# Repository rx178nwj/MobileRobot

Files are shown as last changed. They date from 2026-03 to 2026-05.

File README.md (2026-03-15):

# Mobile Robot

4輪駆動移動ロボットプロジェクト - ROS 2、Python WebSocket サービス、PR2040 モータードライバを使用

## プロジェクト概要

このプロジェクトは、Raspberry Pi と PR2040 マイコンを使用した移動ロボットシステムです。ROS 2 (Jazzy) を Docker コンテナで実行し、Python ベースの Edge Services を介してハードウェアと通信します。

### 主な特徴

- **ROS 2 Jazzy** - Docker コンテナで実行（Debian 13 ホスト）
- **WebSocket 通信** - ROS 2 と Edge Services 間の通信
- **USB シリアル制御** - PR2040 モータードライバとの通信
- **リアルタイムオドメトリ** - 50Hz でのエンコーダベース位置推定
- **差動駆動制御** - 4輪駆動の差動駆動キネマティクス
- **速度制御モード** - PR2040 ファームウェアによる PID 速度制御

## システムアーキテクチャ

```
┌─────────────────────────────────────────────────────────────┐
│                    ROS 2 (Docker Container)                  │
│  ┌──────────────┐  ┌──────────────┐  ┌──────────────┐      │
│  │ ws_motor_    │  │ ws_odometry_ │  │ robot_state_ │      │
│  │ controller   │  │ publisher    │  │ publisher    │      │
│  └──────┬───────┘  └───────▲──────┘  └──────────────┘      │
└─────────┼──────────────────┼────────────────────────────────┘
          │                  │
       WebSocket          WebSocket
       (port 8001)        (port 8002)
          │                  │
          ▼                  ▼
┌─────────────────────────────────────────────────────────────┐
│                      Edge Services (Host)                    │
│  ┌──────────────┐  ┌──────────────┐  ┌──────────────┐      │
│  │ Motor        │  │ Odometry     │  │ Camera       │      │
│  │ Service      │  │ Service      │  │ Service      │      │
│  └──────┬───────┘  └───────▲──────┘  └──────────────┘      │
└─────────┼──────────────────┼────────────────────────────────┘
          │                  │
       USB Serial        USB Serial
       (/dev/ttyACM0)    (/dev/ttyACM0)
          │                  │
          ▼                  ▼
┌─────────────────────────────────────────────────────────────┐
│                  PR2040 Motor Driver                         │
│  ┌──────────┐  ┌──────────┐  ┌──────────┐  ┌──────────┐   │
│  │ Motor 0  │  │ Motor 1  │  │ Motor 2  │  │ Motor 3  │   │
│  │ (動作OK) │  │ (動作OK) │  │ (故障)   │  │ (故障)   │   │
│  └──────────┘  └──────────┘  └──────────┘  └──────────┘   │
└─────────────────────────────────────────────────────────────┘
```

## ハードウェア

- **Raspberry Pi 4** - メインコントローラ
- **PR2040 (RP2040)** - モータードライバマイコン
- **JGA25-370 モーター** - ギア比 51:1、エンコーダ付き
- **車輪**: 直径 66mm (半径 33mm)
- **ホイールベース**: 160mm

### キャリブレーション値

- **エンコーダ CPR**: 827.2 counts/revolution（キャリブレーション済み）
- **ギア比**: 54.78:1（実測値、ファームウェアに組み込み済み）
- **車輪円周**: 212.06mm
- **変換係数**: 0.2564 mm/count

## ディレクトリ構成

```
MobileRobot/
├── edge_services/              # Python WebSocket サービス
│   ├── hardware/              # ハードウェアドライバ
│   │   ├── pr2040_usb_driver.py    # USB シリアルドライバ (使用中)
│   │   └── pr2040_driver.py        # I2C ドライバ (非推奨)
│   ├── config/                # 設定ファイル
│   │   └── robot_config.json  # ロボット設定
│   ├── motor_service.py       # モーター制御サービス (WS:8001)
│   ├── odometry_service.py    # オドメトリサービス (WS:8002)
│   ├── camera_service.py      # カメラサービス (WS:8003)
│   └── launch_all.py          # 全サービス起動スクリプト
│
├── ros2_docker/               # ROS 2 Docker 環境
│   ├── Dockerfile             # ROS 2 Jazzy イメージ
│   └── docker-compose.yml     # Docker Compose 設定
│
├── mobile_robot_edge/         # ROS 2 パッケージ
│   ├── mobile_robot_edge/
│   │   ├── ws_motor_controller.py      # /cmd_vel → WS ブリッジ
│   │   └── ws_odometry_publisher.py    # WS → /odom ブリッジ
│   ├── launch/
│   │   └── ws_edge_bringup.launch.py   # 起動ファイル
│   ├── urdf/
│   │   └── mobile_robot.urdf           # ロボットモデル
│   ├── package.xml
│   └── setup.py
│
├── MotorDriver/               # PR2040 ファームウェア
│   └── Firmware/
│       └── PR2040_MotorDriver/
│           ├── PR2040_MotorDriver.ino  # メインファームウェア
│           └── CommandReference.md     # 通信プロトコル仕様
│
├── docs/                      # ドキュメント
│   └── raspberry_pi_setup.md  # Raspberry Pi セットアップガイド
│
└── test_*.py                  # 各種テストスクリプト
```

## セットアップ

### クイックスタート

```bash
# 1. リポジトリのクローン
git clone https://github.com/rx178nwj/MobileRobot.git
cd MobileRobot

# 2. 詳細なセットアップ手順に従う
# docs/raspberry_pi_setup.md を参照してください
```

### 詳細なセットアップ

完全なセットアップ手順については、以下のドキュメントを参照してください:

📚 **[Raspberry Pi セットアップガイド](docs/raspberry_pi_setup.md)**

このガイドには以下が含まれます:
- システム要件
- Docker インストール
- Python 環境セットアップ
- ハードウェア接続確認
- Edge Services セットアップ
- ROS 2 Docker 環境セットアップ
- システムの起動方法
- トラブルシューティング

## 使い方

### システムの起動

#### 1. Edge Services の起動（ターミナル 1）

```bash
cd ~/MobileRobot/edge_services
python3 launch_all.py
```

#### 2. ROS 2 システムの起動（ターミナル 2）

```bash
cd ~/MobileRobot/ros2_docker
docker compose run --rm ros2 bash -c "
    source /opt/ros/jazzy/setup.bash && \
    source /home/pi/ros2_ws/install/setup.bash && \
    ros2 launch mobile_robot_edge ws_edge_bringup.launch.py
"
```

#### 3. ロボットの制御（ターミナル 3）

```bash
cd ~/MobileRobot/ros2_docker
docker compose run --rm ros2 bash

# コンテナ内で
source /opt/ros/jazzy/setup.bash
source /home/pi/ros2_ws/install/setup.bash

# 前進コマンド
ros2 topic pub --once /cmd_vel geometry_msgs/msg/Twist \
    "{linear: {x: 0.1, y: 0.0, z: 0.0}, angular: {x: 0.0, y: 0.0, z: 0.0}}"

# オドメトリの確認
ros2 topic echo /odom
```

### テスト

#### 総合テストスイート

```bash
cd ~/MobileRobot
python3 test_usb_services.py
```

#### モーター個別テスト

```bash
# 各モーターを個別にテスト（DIRECT モード）
python3 test_motors_complete.py --test direct

# 10cm 前進テスト（VELOCITY モード）
python3 test_motors_complete.py --test velocity
```

#### USB 通信テスト

```bash
# 基本的な USB 通信テスト
python3 test_pr2040_usb_fixed.py --test basic

# 10cm 移動テスト
python3 test_pr2040_usb_fixed.py --test move
```

## 通信プロトコル

### USB シリアルプロトコル

PR2040 との通信は以下のパケット形式を使用:

```
[0xAA][CMD][LEN][DATA...][CHECKSUM]
```

- **Header**: 0xAA（固定）
- **CMD**: コマンドバイト
- **LEN**: データ長
- **DATA**: コマンドデータ
- **CHECKSUM**: XOR チェックサム（CMD ^ LEN ^ DATA[0] ^ ... ^ DATA[LEN-1]）

詳細は [CommandReference.md](MotorDriver/Firmware/PR2040_MotorDriver/CommandReference.md) を参照。

### WebSocket プロトコル

#### モーター制御（ポート 8001）

```json
{
  "type": "cmd_vel",
  "linear": 0.1,    // m/s
  "angular": 0.5    // rad/s
}
```

#### オドメトリ（ポート 8002）

```json
{
  "type": "odom",
  "timestamp": 1234567.89,
  "pose": {
    "x": 0.0,       // meters
    "y": 0.0,       // meters
    "theta": 0.0    // radians
  },
  "twist": {
    "linear": 0.0,  // m/s
    "angular": 0.0  // rad/s
  },
  "encoders": [100, 100, 0, 0]
}
```

## 既知の問題

### ハードウェア

- **モーター 2 と 3**: ハードウェアの問題により動作しません（エンコーダ値が常に 0）
- **モーター 0 と 1**: 正常に動作します

### 対応予定

これらのハードウェア問題は、モータードライバボードまたは配線の問題と考えられます。

## 開発状況

### 完了

- ✅ PR2040 ファームウェア（USB シリアル + I2C）
- ✅ USB シリアルドライバ
- ✅ Edge Services（モーター制御、オドメトリ、カメラ）
- ✅ ROS 2 Docker 環境
- ✅ WebSocket ブリッジ
- ✅ 基本的な動作確認

### 今後の予定

- ⏳ IMU センサー統合
- ⏳ カメラ画像処理
- ⏳ ナビゲーションスタック（Nav2）
- ⏳ SLAM（地図作成と自己位置推定）
- ⏳ 自律ナビゲーション

## ライセンス

このプロジェクトは MIT ライセンスの下で公開されています。

## 貢献

プルリクエストを歓迎します。大きな変更の場合は、まず issue を開いて変更内容を議論してください。

## 作者

- GitHub: [@rx178nwj](https://github.com/rx178nwj)

## 謝辞

- ROS 2 コミュニティ
- Raspberry Pi Foundation
- Arduino/RP2040 コミュニティ

---

**最終更新日**: 2026-03-15

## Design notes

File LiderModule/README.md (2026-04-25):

# LiderModule

LiderModule is a low-cost 3D LiDAR scanner module for a mobile robot. It tilts a 2D YDLIDAR T-mini Pro with a FEETECH STS3215 servo, reads MPU6050 attitude data on the ESP32-S3, and sends scan slices to a Raspberry Pi over USB CDC.

Design policy:

- LiderModule firmware focuses on sensing quality (LiDAR + tilt angle + IMU + timing consistency).
- Environment understanding (step/hole detection, risk decision, vehicle action) is implemented on Raspberry Pi side.

## Implementation Status

Implemented:

- ESP32-S3 Arduino firmware in `firmware/lidar_tilt_3d/lidar_tilt_3d.ino`
- Raspberry Pi host CLI in `host/rpi_tilt_3d.py`
- Binary USB CDC framing compatible with `SPEC.md`
- IMU packets, 3D scan status packets, 3D scan slice packets
- Manual tilt command and automatic tilt scan command
- Point-cloud transform, CSV export, PLY export, and optional Open3D/matplotlib visualization

Needs hardware validation:

- Exact YDLIDAR T-mini Pro packet distance scaling and checksum behavior
- SCServo library API compatibility for the installed Arduino library version
- Servo direction and center position on the assembled mechanism
- Final IMU sign convention after physical mounting

The requirements are implementable, but those items depend on the actual hardware, library version, and mounting orientation.

## Layout

```text
LiderModule/
  SPEC.md
  README.md
  firmware/
    lidar_tilt_3d/
      lidar_tilt_3d.ino
  host/
    rpi_tilt_3d.py
    requirements.txt
    test_protocol.py
  docs/
    wiring.md
```

## Firmware Setup

1. Install Arduino IDE 2.x.
2. Select `Seeed Studio XIAO ESP32-S3`.
3. Enable `USB CDC On Boot`.
4. Install the `SCServo` library.
5. Open `firmware/lidar_tilt_3d/lidar_tilt_3d.ino`.
6. Upload to the XIAO ESP32-S3.

Important serial assignments:

- `Serial`: USB CDC to Raspberry Pi
- `Serial0`: STS3215 servo bus, 1 Mbps, GPIO44 RX / GPIO43 TX
- `LidarSerial`: YDLIDAR, 230400 bps, GPIO3 RX / GPIO4 TX

## Host Setup

```bash
cd LiderModule/host
python3 -m venv .venv
. .venv/bin/activate
pip install -r requirements.txt
```

Default scan (continuous sweep, no step-stop):

```bash
python3 rpi_tilt_3d.py --port /dev/ttyACM0
```

Save a PLY point cloud:

```bash
python3 rpi_tilt_3d.py --tilt-min -45 --tilt-max 45 --step 2 --save scan.ply
```

Save CSV without visualization:

```bash
python3 rpi_tilt_3d.py --step 2 --save scan.csv --no-viz
```

Visualize saved result (.csv / .ply):

```bash
python3 host/visualize_scan_result.py scan.ply --mode matplotlib
python3 host/visualize_scan_result.py scan.csv --mode both --equal-axis
python3 host/visualize_scan_result.py scan.ply --save-png scan_summary.png --no-show
```

Continuous live visualization (for remote desktop):

```bash
python3 host/live_scan_viewer.py --port /dev/ttyACM0 --tilt-min -45 --tilt-max 45 --step 2 --equal-axis --auto-recover
```

`live_scan_viewer.py` のウィンドウ右下に `Clear` ボタンがあり、押すと表示中の点群だけをクリアします（計測は継続）。
同ウィンドウには `Height-wise Y Graph (Y-Z)` が追加され、高さ(Z)ごとのY分布を確認できます。

Downward hazard monitoring example on Raspberry Pi side:

```bash
python3 host/downward_hazard_monitor.py --port /dev/ttyACM1 --tilt-min -45 --tilt-max 0 --step 2 --duration-sec 20 --save-png downward_hazard_summary.png
```

This mode continuously scans the downward sector and prints hazard status (`SAFE` / `STEP_DOWN` / `HOLE`) while running.

Manual tilt test:

```bash
python3 rpi_tilt_3d.py --manual-tilt 30.0 --no-viz
```

## Protocol Summary

Frames use:

```text
[0xFE][0xEF][TYPE][LEN_L][LEN_H][PAYLOAD...][CHECKSUM]
```

The checksum is XOR of `TYPE`, `LEN_L`, `LEN_H`, and all payload bytes.

Device to host:

- `0x02`: IMU data, `<float pitch><float roll><float yaw>`
- `0x04`: scan slice, `<float tilt_cmd><float tilt_start><float tilt_end><float imu_pitch><float imu_roll><uint16 count><points...>`
- `0x05`: scan status, `<uint8 state><uint16 step><uint16 total>`

Host to device:

- `0x10`: manual servo angle, `<float angle_deg>`
- `0x12`: scan start, `<float tilt_min><float tilt_max><float step>`
- `0x13`: scan stop, empty payload

## Validation

Host-side syntax and protocol tests:

```bash
cd LiderModule/host
python -m py_compile rpi_tilt_3d.py test_protocol.py
python -m unittest test_protocol.py
```

Firmware validation must be completed in Arduino IDE or `arduino-cli` with the target board package and `SCServo` installed.

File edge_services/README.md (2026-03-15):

# Edge Services

シンプルなPythonベースのモバイルロボットエッジ制御サービス

## 概要

Raspberry Pi上で動作する軽量なロボット制御サービス群です。ROS 2を使用せず、WebSocket通信で外部PCと連携します。

### アーキテクチャ

```
外部PC (ROS 2)  ←→  WebSocket  ←→  Raspberry Pi (Edge Services)
                                          ↓ I2C
                                    PR2040 Motor Driver
```

## 機能

### 1. モーター制御サービス (`motor_service.py`)
- WebSocketで速度指令を受信
- 差動駆動キネマティクス
- I2C経由でPR2040モータードライバ制御
- 安全タイムアウト機能

**WebSocket**: `ws://raspberrypi.local:8001`

**メッセージフォーマット**:
```json
{
  "type": "cmd_vel",
  "linear": 0.2,   // m/s
  "angular": 0.5   // rad/s
}
```

### 2. オドメトリサービス (`odometry_service.py`)
- エンコーダ読み取り (I2C)
- オドメトリ計算 (位置・速度)
- WebSocketで配信 (50Hz)

**WebSocket**: `ws://raspberrypi.local:8002`

**メッセージフォーマット**:
```json
{
  "type": "odom",
  "timestamp": 1234567.89,
  "pose": {
    "x": 0.0,      // meters
    "y": 0.0,      // meters
    "theta": 0.0   // radians
  },
  "twist": {
    "linear": 0.0,  // m/s
    "angular": 0.0  // rad/s
  },
  "encoders": [0, 0, 0, 0]
}
```

### 3. カメラサービス (`camera_service.py`)
- Raspberry Pi Camera Module 3から画像取得
- オートフォーカス無効化 (SLAM用)
- JPEG圧縮配信
- WebSocket配信 (30fps)

**WebSocket**: `ws://raspberrypi.local:8003`

**メッセージフォーマット**: バイナリ (ヘッダー8バイト + JPEGデータ)

## ファイル構成

```
edge_services/
├── hardware/
│   ├── __init__.py
│   └── pr2040_driver.py      # PR2040 I2C通信ライブラリ
├── config/
│   └── robot_config.json     # ロボット設定
├── logs/                     # ログファイル
├── motor_service.py          # モーター制御サービス
├── odometry_service.py       # オドメトリサービス
├── camera_service.py         # カメラサービス
├── launch_all.py             # 全サービス起動スクリプト
├── requirements.txt          # Python依存関係
└── README.md                 # 本ドキュメント
```

## セットアップ

### 1. 依存パッケージのインストール

```bash
cd /home/pi/MobileRobot/edge_services

# Pythonパッケージ
pip3 install -r requirements.txt

# システムパッケージ
sudo apt install -y python3-opencv i2c-tools v4l-utils
```

### 2. I2C有効化

```bash
# raspi-configでI2Cを有効化
sudo raspi-config
# Interface Options → I2C → Yes

# I2Cデバイス確認
i2cdetect -y 1
# 0x60にPR2040が表示されるはず
```

### 3. カメラ設定

```bash
# カメラデバイス確認
ls -l /dev/video0

# カメラ情報確認
v4l2-ctl -d /dev/video0 --all

# フォーカス値の調整（オプション）
v4l2-ctl -d /dev/video0 --set-ctrl=focus_automatic_continuous=0
v4l2-ctl -d /dev/video0 --set-ctrl=focus_absolute=450
```

### 4. 設定ファイル編集

`config/robot_config.json`を編集してロボットパラメータを調整:

```json
{
  "robot": {
    "wheel_base": 0.16,     // 車輪間距離 (m)
    "wheel_radius": 0.033,  // 車輪半径 (m)
    "encoder_cpr": 720      // エンコーダ分解能
  }
}
```

## 起動方法

### すべてのサービスを起動

```bash
cd /home/pi/MobileRobot/edge_services
python3 launch_all.py
```

### 個別サービスの起動

```bash
# モーター制御のみ
python3 motor_service.py

# オドメトリのみ
python3 odometry_service.py

# カメラのみ
python3 camera_service.py
```

### systemdサービスとして登録（自動起動）

```bash
# サービスファイル作成
sudo nano /etc/systemd/system/edge-services.service
```

```ini
[Unit]
Description=Mobile Robot Edge Services
After=network.target

[Service]
Type=simple
User=pi
WorkingDirectory=/home/pi/MobileRobot/edge_services
ExecStart=/usr/bin/python3 /home/pi/MobileRobot/edge_services/launch_all.py
Restart=on-failure
RestartSec=5

[Install]
WantedBy=multi-user.target
```

```bash
# サービス有効化
sudo systemctl daemon-reload
sudo systemctl enable edge-services
sudo systemctl start edge-services

# ステータス確認
sudo systemctl status edge-services

# ログ確認
sudo journalctl -u edge-services -f
```

## テスト

### WebSocketテスト (Python)

```python
import asyncio
import websockets
import json

async def test_motor():
    uri = "ws://localhost:8001"
    async with websockets.connect(uri) as ws:
        # 前進指令
        cmd = {"type": "cmd_vel", "linear": 0.2, "angular": 0.0}
        await ws.send(json.dumps(cmd))
        response = await ws.recv()
        print(f"Motor response: {response}")

async def test_odometry():
    uri = "ws://localhost:8002"
    async with websockets.connect(uri) as ws:
        # オドメトリ受信
        for i in range(10):
            msg = await ws.recv()
            data = json.loads(msg)
            print(f"Odom: x={data['pose']['x']:.3f} y={data['pose']['y']:.3f}")

asyncio.run(test_motor())
asyncio.run(test_odometry())
```

### I2C通信テスト

```bash
# PR2040ドライバテスト
cd /home/pi/MobileRobot/edge_services
python3 -c "from hardware.pr2040_driver import PR2040Driver; \
driver = PR2040Driver(); \
print('Temp:', driver.read_temperature()); \
print('Encoders:', driver.read_all_encoders()); \
driver.close()"
```

## トラブルシューティング

### I2C通信エラー

```bash
# I2Cデバイス確認
i2cdetect -y 1

# PR2040が0x60に表示されない場合:
# - 配線を確認
# - PR2040の電源を確認
# - I2Cプルアップ抵抗を確認
```

### カメラが起動しない

```bash
# カメラデバイス確認
ls -l /dev/video*

# カメラが検出されない場合:
sudo vcgencmd get_camera

# カメラを有効化
sudo raspi-config
# Interface Options → Camera → Yes
# 再起動が必要
```

### WebSocketに接続できない

```bash
# ポートが開いているか確認
sudo netstat -tuln | grep 800

# ファイアウォール確認（Debian/Raspberry Pi OSではデフォルトで無効）
sudo ufw status

# サービスログ確認
tail -f logs/edge_services.log
```

## 外部PCとの連携 (ROS 2ブリッジ)

外部PC側で ROS 2 ブリッジノードを作成すると、ROS 2 Navigation Stackと連携できます。

### ROS 2ブリッジノード例

```python
# 外部PC (ROS 2) 側
import rclpy
from rclpy.node import Node
from geometry_msgs.msg import Twist
from nav_msgs.msg import Odometry
import asyncio
import websockets

class EdgeBridgeNode(Node):
    def __init__(self):
        super().__init__('edge_bridge')

        # ROS 2トピック
        self.cmd_vel_sub = self.create_subscription(
            Twist, '/cmd_vel', self.cmd_vel_callback, 10)
        self.odom_pub = self.create_publisher(Odometry, '/odom', 10)

        # WebSocket接続 (Raspberry Pi)
        self.motor_ws = "ws://raspberrypi.local:8001"
        self.odom_ws = "ws://raspberrypi.local:8002"

    # ... 実装 ...
```

## パラメータ調整

### フォーカス値の最適化

ロボットの動作環境に応じてカメラのフォーカス値を調整:

- **近距離** (20-50cm): `focus_value: 200-350`
- **中距離** (50cm-2m): `focus_value: 400-500`
- **遠距離** (1m-∞): `focus_value: 500-650`

### PIDゲイン調整

PR2040ドライバでPIDゲインを調整可能:

```python
from hardware.pr2040_driver import PR2040Driver

driver = PR2040Driver()

# 速度PIDゲイン設定 (wheel_index, kp, ki, kd)
# デフォルト: kp=1.0, ki=0.05, kd=0.0
kp, ki, kd = 1.5, 0.1, 0.0
data = struct.pack('<Bfff', 0, kp, ki, kd)
driver._write_register(driver.REG_SET_VEL_PID, list(data))
```

## ライセンス

MIT

## 作者

rx178nwj

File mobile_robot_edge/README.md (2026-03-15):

# mobile_robot_edge

ROS 2 Humbleパッケージ - モバイルロボットのエッジ側制御（Raspberry Pi）

## 概要

このパッケージはRaspberry Pi上で動作し、センサーデータの取得とモーター制御を担当します。
重い処理（SLAM、ナビゲーション等）は別のPCで実行されることを想定しています。

## ハードウェア要件

- **SBC**: Raspberry Pi 4/5 (Ubuntu 22.04)
- **カメラ**: Raspberry Pi Camera Module 3
- **モータードライバ**: PR2040 Motor Driver (I2C: 0x60)
- **モーター**: 4輪駆動DC モーター with エンコーダ

## 機能

### 1. カメラノード
- Raspberry Pi Camera Module 3からの画像配信
- **オートフォーカス無効化** (SLAM安定化のため)
- 圧縮画像配信 (ネットワーク帯域節約)
- トピック: `/camera/image_raw/compressed`

### 2. オドメトリ配信
- 車輪エンコーダからの位置推定
- トピック: `/odom` (nav_msgs/Odometry)
- TF配信: `odom` → `base_footprint`

### 3. モーター制御
- `/cmd_vel` 購読してモーター制御
- 差動駆動キネマティクス
- 安全タイムアウト機能

## ビルド方法

```bash
cd ~/ros2_ws
colcon build --packages-select mobile_robot_edge
source install/setup.bash
```

## 起動方法

### 全機能を一括起動
```bash
ros2 launch mobile_robot_edge edge_bringup.launch.py
```

### 個別起動

**カメラのみ:**
```bash
ros2 launch mobile_robot_edge camera.launch.py
```

**オドメトリのみ:**
```bash
ros2 run mobile_robot_edge odometry_publisher
```

**モーター制御のみ:**
```bash
ros2 run mobile_robot_edge motor_controller
```

## ハードウェア統合手順

現在、エンコーダ読み取りとモーター制御は**テンプレート実装**です。
実際のハードウェアを接続する際は、以下のファイルの`TODO`セクションを実装してください。

### 1. オドメトリ配信ノード

**ファイル**: `mobile_robot_edge/odometry_publisher.py`

**実装箇所:**

#### `init_hardware()` メソッド
```python
# TODO: I2C初期化
import smbus2
self.i2c_bus = smbus2.SMBus(1)  # I2C bus 1
```

#### `read_encoders()` メソッド
```python
# TODO: PR2040からエンコーダ値を読み取る
# レジスタアドレス:
#   REG_ENC0 = 0x10  # Left front
#   REG_ENC1 = 0x11  # Right front
#   REG_ENC2 = 0x12  # Left rear
#   REG_ENC3 = 0x13  # Right rear

import struct
left_front = self.read_i2c_register(0x10, 4)
left_rear = self.read_i2c_register(0x12, 4)
left_enc = (struct.unpack('<i', left_front)[0] +
           struct.unpack('<i', left_rear)[0]) // 2
# ... (right側も同様)
```

#### `read_i2c_register()` メソッド
```python
# TODO: I2Cレジスタ読み取り実装
self.i2c_bus.write_byte(self.i2c_address, register)
data = self.i2c_bus.read_i2c_block_data(self.i2c_address, register, num_bytes)
return bytes(data)
```

### 2. モーター制御ノード

**ファイル**: `mobile_robot_edge/motor_controller.py`

**実装箇所:**

#### `init_hardware()` メソッド
```python
# TODO: I2C初期化とモード設定
import smbus2
self.i2c_bus = smbus2.SMBus(1)

# 速度制御モードに設定
REG_SET_MODE_ALL = 0x06
mode_data = [REG_SET_MODE_ALL, 1, 1, 1, 1]  # All to velocity mode
self.i2c_bus.write_i2c_block_data(self.i2c_address, mode_data[0], mode_data[1:])
```

#### `set_wheel_velocities()` メソッド
```python
# TODO: モーター速度指令を送信
import struct

REG_SET_VEL_ALL = 0x08
velocities = struct.pack('<ffff',
                        left_cps,   # Wheel 0 (left front)
                        right_cps,  # Wheel 1 (right front)
                        left_cps,   # Wheel 2 (left rear)
                        right_cps)  # Wheel 3 (right rear)

data = [REG_SET_VEL_ALL] + list(velocities)
self.i2c_bus.write_i2c_block_data(self.i2c_address, data[0], data[1:])
```

### 3. カメラオートフォーカス設定

**ファイル**: `mobile_robot_edge/disable_camera_autofocus.sh`

起動前に実行して、フォーカス値を調整してください:

```bash
# フォーカス値の確認
v4l2-ctl -d /dev/video0 --list-ctrls | grep focus

# フォーカス値の調整（ロボットの動作距離に応じて）
# 近距離 (20-50cm): 200-350
# 中距離 (50cm-2m): 400-500
# 遠距離 (1m-infinity): 500-650
```

## パラメータ設定

`edge_bringup.launch.py`でパラメータを調整できます:

```python
parameters=[{
    'wheel_base': 0.16,              # 車輪間距離 (m)
    'wheel_radius': 0.033,           # 車輪半径 (m)
    'encoder_cpr': 720,              # エンコーダ分解能
    'max_linear_velocity': 0.5,      # 最大直進速度 (m/s)
    'max_angular_velocity': 2.0,     # 最大角速度 (rad/s)
    'i2c_address': 0x60,             # I2Cアドレス
}]
```

## トピック

### Published
- `/odom` (nav_msgs/Odometry) - オドメトリ情報
- `/camera/image_raw/compressed` (sensor_msgs/CompressedImage) - カメラ画像
- `/tf` (tf2_msgs/TFMessage) - 座標変換

### Subscribed
- `/cmd_vel` (geometry_msgs/Twist) - 速度指令

## TFツリー

```
odom
└── base_footprint
    └── base_link
        └── camera_link
            └── camera_optical_frame
```

## 依存パッケージ

```bash
sudo apt install ros-humble-v4l2-camera
sudo apt install ros-humble-image-transport
sudo apt install ros-humble-image-transport-plugins
sudo apt install ros-humble-robot-state-publisher
pip3 install smbus2  # I2C通信用
```

## トラブルシューティング

### カメラが起動しない
```bash
# カメラデバイスを確認
ls -l /dev/video*

# v4l2-ctlでカメラ情報確認
v4l2-ctl -d /dev/video0 --all
```

### I2C通信エラー
```bash
# I2Cデバイスを確認
i2cdetect -y 1

# 0x60にモータードライバが表示されるはず
```

### オドメトリが更新されない
- `init_hardware()`と`read_encoders()`のTODO実装を確認
- I2C接続とアドレスを確認

## ライセンス

MIT

## 作者

rx178nwj

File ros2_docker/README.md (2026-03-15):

# ROS 2 Jazzy Docker Setup

このディレクトリは、Raspberry Pi上でROS 2 JazzyをDockerコンテナとして実行するための設定ファイルを含んでいます。

## 概要

Debian 13 (trixie) では ROS 2 のネイティブインストールに依存関係の問題があるため、Docker環境でROS 2を実行します。

## ファイル構成

- `Dockerfile` - ROS 2 Jazzy ベースイメージの定義
- `docker-compose.yml` - コンテナ設定とデバイスマッピング
- `README.md` - 本ドキュメント

## 使用方法

### イメージのビルド

```bash
cd /home/pi/MobileRobot/ros2_docker
docker-compose build
```

初回ビルドは15-30分程度かかる場合があります。

### コンテナの起動

```bash
# コンテナを起動してbashシェルに入る
docker-compose run --rm ros2

# または、バックグラウンドで起動
docker-compose up -d
docker exec -it mobile_robot_ros2 bash
```

### ROS 2の動作確認

コンテナ内で:

```bash
# ROS 2のバージョン確認
ros2 --version

# ノードのリスト表示
ros2 node list

# トピックのリスト表示
ros2 topic list
```

### ワークスペースのビルド

```bash
# コンテナ内で
cd /ros2_ws
colcon build --packages-select mobile_robot_edge
source install/setup.bash
```

### ハードウェアアクセス

以下のデバイスがコンテナにマウントされています:

- `/dev/i2c-1` - I2C通信 (PR2040との通信)
- `/dev/video0` - カメラデバイス (Raspberry Pi Camera Module 3)

#### I2C動作確認

```bash
# コンテナ内で
i2cdetect -y 1
# 0x60にPR2040が表示されるはず
```

#### カメラ動作確認

```bash
# コンテナ内で
v4l2-ctl -d /dev/video0 --list-formats-ext
```

## アーキテクチャ

### システム構成

```
┌─────────────────────────────────────────┐
│ Raspberry Pi (Debian 13)               │
│                                         │
│  ┌───────────────────────────────────┐ │
│  │ Docker Container (Ubuntu 24.04)   │ │
│  │                                   │ │
│  │  ┌─────────────────────────────┐ │ │
│  │  │ ROS 2 Jazzy                 │ │ │
│  │  │ - Navigation Stack          │ │ │
│  │  │ - SLAM Toolbox              │ │ │
│  │  │ - Robot State Publisher     │ │ │
│  │  └─────────────────────────────┘ │ │
│  │                                   │ │
│  │  ┌─────────────────────────────┐ │ │
│  │  │ mobile_robot_edge package   │ │ │
│  │  │ - Camera launch             │ │ │
│  │  │ - Edge bringup              │ │ │
│  │  └─────────────────────────────┘ │ │
│  └───────────────────────────────────┘ │
│           ↓ (device mapping)           │
│  ┌───────────────────────────────────┐ │
│  │ Edge Services (Python)            │ │
│  │ - motor_service.py   (WS:8001)    │ │
│  │ - odometry_service.py (WS:8002)   │ │
│  │ - camera_service.py  (WS:8003)    │ │
│  └───────────────────────────────────┘ │
│           ↓ I2C (/dev/i2c-1)           │
│  ┌───────────────────────────────────┐ │
│  │ PR2040 Motor Driver (0x60)        │ │
│  └───────────────────────────────────┘ │
└─────────────────────────────────────────┘
```

### 通信フロー

1. **外部PC → ROS 2 (Docker内)**
   - ROS 2 ノード間通信 (DDS)
   - Navigation指令、SLAMデータなど

2. **ROS 2 (Docker内) → Edge Services**
   - WebSocket通信 (localhost:8001-8003)
   - cmd_vel指令、オドメトリ、カメラ画像

3. **Edge Services → PR2040**
   - I2C通信 (/dev/i2c-1, address 0x60)
   - モーター制御、エンコーダ読み取り

## トラブルシューティング

### イメージビルドエラー

```bash
# キャッシュをクリアして再ビルド
docker-compose build --no-cache
```

### デバイスアクセスエラー

```bash
# I2Cデバイスの権限確認
ls -l /dev/i2c-1

# 必要に応じて権限変更
sudo chmod 666 /dev/i2c-1
sudo chmod 666 /dev/video0
```

### コンテナが起動しない

```bash
# ログを確認
docker-compose logs

# 既存のコンテナを削除
docker-compose down
docker-compose up
```

## メモ

- コンテナは `privileged` モードで実行されます (ハードウェアアクセスのため)
- `network_mode: host` により、ホストのネットワークを共有します
- ROS 2のDDS通信は `ROS_DOMAIN_ID=0` で設定されています

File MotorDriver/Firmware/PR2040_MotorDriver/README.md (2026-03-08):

# PR2040_MotorDriver Firmware

RP2040 搭載 4ch DCモータドライバボード用 Arduino ファームウェア

- **ハードウェア**: PR2040_BASESYSTEM REV1.5.0 (N.W Works)
- **MCU**: RP2040
- **Arduinoコア**: [arduino-pico (Earle Philhower)](https://github.com/earlephilhower/arduino-pico)

---

## ファイル構成

```
PR2040_MotorDriver/
├── PR2040_MotorDriver.ino   メインスケッチ・通信プロトコル処理
├── Config.h                 GPIOピン定義・プロトコル定数・レジスタマップ
├── Motor.h / Motor.cpp      TB67H451 モータドライバクラス
├── Encoder.h / Encoder.cpp  直交エンコーダクラス（割り込みベース）
├── PID.h / PID.cpp          PIDコントローラ（アンチワインドアップ付き）
├── WheelController.h / .cpp 速度・位置制御クラス
└── README.md                本ドキュメント
```

---

## ハードウェア構成

| コンポーネント | 型番 | 個数 |
|---|---|---|
| MCU | RP2040 | 1 |
| モータドライバ | TB67H451 (H-bridge) | 4 |
| 電流センサ | INA21x SC70 | 4 |
| 外部ADC | MCP3208 / MAX11125 (SPI) | 1 |
| IMU | MPU-6881 (6軸 I2C) | 1 |
| SPI Flash | W25Q128 (16MB) | 1 |

---

## GPIOピンアサイン

### モータ制御 (TB67H451)

| モータ | IN1 | IN2 |
|---|---|---|
| Motor 1 | GPIO8 | GPIO9 |
| Motor 2 | GPIO10 | GPIO11 |
| Motor 3 | GPIO14 | GPIO15 |
| Motor 4 | GPIO16 | GPIO17 |

### エンコーダ入力

| エンコーダ | チャンネルA | チャンネルB |
|---|---|---|
| Encoder 1 (Motor 1) | GPIO18 | GPIO19 |
| Encoder 2 (Motor 2) | GPIO20 | GPIO21 |
| Encoder 3 (Motor 3) | GPIO22 | GPIO23 |
| Encoder 4 (Motor 4) | GPIO24 | GPIO25 |

### 通信・周辺機能

| 機能 | GPIO | 備考 |
|---|---|---|
| I2C1 SDA (コントローラ通信) | GPIO2 | Wire1 スレーブ |
| I2C1 SCL (コントローラ通信) | GPIO3 | Wire1 スレーブ |
| SPI0 MISO (外部ADC) | GPIO4 | |
| SPI0 CS (外部ADC) | GPIO5 | |
| SPI0 SCK  (外部ADC) | GPIO6 | |
| SPI0 MOSI (外部ADC) | GPIO7 | |
| I2C0 SDA (MPU-6881) | GPIO12 | Wire マスタ |
| I2C0 SCL (MPU-6881) | GPIO13 | Wire マスタ |
| MPU-6881 INT | GPIO0 | 割り込み入力 |
| ADC0 電流センス | GPIO26 | Motor 1 |
| ADC1 電流センス | GPIO27 | Motor 2 |
| ADC2 電流センス | GPIO28 | Motor 3 |
| ADC3 電流センス | GPIO29 | Motor 4 |

---

## TB67H451 モータ制御ロジック

| IN1 | IN2 | 動作 |
|---|---|---|
| PWM | LOW | 正転（Forward） |
| LOW | PWM | 逆転（Reverse） |
| HIGH | HIGH | アクティブブレーキ |
| LOW | LOW | コースト（慣性停止） |

速度指令値: **-1000 〜 +1000**（正値=正転、負値=逆転、0=コースト）

PWM周波数: **20 kHz**

---

## 車輪制御モード (WheelController)

各車輪は独立した制御モードを持ちます。制御ループは **200 Hz**（5ms間隔）で実行されます。

### モード一覧

| モード | 値 | 内容 |
|---|---|---|
| DIRECT | 0 | デューティ直接指定（-1000〜+1000）。フィードバックなし |
| VELOCITY | 1 | 速度PID制御。目標値: counts/sec (signed float) |
| POSITION | 2 | 位置カスケード制御。目標値: エンコーダカウント (int32) |

### 位置制御カスケード構造

```
目標位置
    │
    ▼
[外側P] posError × posKp → 速度目標 (±maxVelCps でクリップ)
    │
    ▼
[内側PI] 速度誤差 → PID → デューティ (-1000〜+1000)
    │
    ▼
  モータ
```

位置誤差が ±5 counts 以内になるとコースト停止（デッドバンド）。

### デフォルトPIDゲイン

| パラメータ | 値 | 説明 |
|---|---|---|
| Velocity Kp | 1.0 | 速度ループ 比例ゲイン |
| Velocity Ki | 0.05 | 速度ループ 積分ゲイン |
| Velocity Kd | 0.0 | 速度ループ 微分ゲイン |
| Position posKp | 0.5 | 位置ループ 比例ゲイン |
| maxVelCps | 2000 | 位置制御時の最大速度 (counts/sec) |

速度フィルタ: **ローパスフィルタ** (α=0.4, 各制御周期で更新)

---

## I2C スレーブ通信 (Wire1)

**スレーブアドレス**: `0x60`（7bit）
**ピン**: SDA=GPIO2 / SCL=GPIO3

### レジスタマップ

#### 書き込みレジスタ（コントローラ → ボード）

| レジスタ | アドレス | データ長 | 内容 |
|---|---|---|---|
| REG_MOTOR_ALL | 0x01 | 8 B | int16 x4 モータデューティ (little-endian) |
| REG_MOTOR_SINGLE | 0x02 | 3 B | uint8 index(0-3) + int16 duty |
| REG_STOP_ALL | 0x03 | 0 B | 全モータ コースト停止 |
| REG_BRAKE_ALL | 0x04 | 0 B | 全モータ アクティブブレーキ |
| REG_RESET_ENC | 0x05 | 0 B | エンコーダカウントリセット |
| REG_SET_MODE_ALL | 0x06 | 4 B | uint8 x4 制御モード (0=DIRECT/1=VEL/2=POS) |
| REG_SET_MODE_SINGLE | 0x07 | 2 B | uint8 index + uint8 mode |
| REG_SET_VEL_ALL | 0x08 | 16 B | float x4 速度目標 (counts/sec, little-endian) |
| REG_SET_VEL_SINGLE | 0x09 | 5 B | uint8 index + float target |
| REG_SET_POS_ALL | 0x0A | 16 B | int32 x4 位置目標 (counts, little-endian) |
| REG_SET_POS_SINGLE | 0x0B | 5 B | uint8 index + int32 target |
| REG_SET_VEL_PID | 0x0C | 13 B | uint8 index + float kp, ki, kd |
| REG_SET_POS_GAINS | 0x0D | 9 B | uint8 index + float posKp, maxVelCps |

#### 読み出しレジスタ（ボード → コントローラ）

| レジスタ | アドレス | データ長 | 内容 |
|---|---|---|---|
| REG_ENC0 | 0x10 | 4 B | int32 エンコーダ0カウント |
| REG_ENC1 | 0x11 | 4 B | int32 エンコーダ1カウント |
| REG_ENC2 | 0x12 | 4 B | int32 エンコーダ2カウント |
| REG_ENC3 | 0x13 | 4 B | int32 エンコーダ3カウント |
| REG_VEL0 | 0x14 | 4 B | int32 車輪0速度 (counts/sec) |
| REG_VEL1 | 0x15 | 4 B | int32 車輪1速度 |
| REG_VEL2 | 0x16 | 4 B | int32 車輪2速度 |
| REG_VEL3 | 0x17 | 4 B | int32 車輪3速度 |
| REG_ADC0 | 0x20 | 2 B | int16 ADC ch0 (0..4095) |
| REG_ADC1 | 0x21 | 2 B | int16 ADC ch1 |
| REG_ADC2 | 0x22 | 2 B | int16 ADC ch2 |
| REG_ADC3 | 0x23 | 2 B | int16 ADC ch3 |
| REG_STATUS | 0x30 | 44 B | 全ステータス（後述） |
| REG_DEVICE_ID | 0xFF | 2 B | `0x20 0x40` |

#### REG_STATUS レイアウト (44 bytes)

```
[  0..15] int32 x4  encoder 0..3 counts (little-endian)
[ 16..31] int32 x4  velocity 0..3 (counts/sec, little-endian)
[ 32..39] int16 x4  ADC ch0..3 raw (0..4095, little-endian)
[ 40..43] uint32    timestamp (ms, millis())
```

### I2C 操作例

```
// 速度制御モード設定（全軸）
Write: [0x60+W] [0x06] [0x01, 0x01, 0x01, 0x01]

// 車輪0の速度目標設定 (500.0 counts/sec)
// float 500.0 = 0x43FA0000 (little-endian: 0x00, 0x00, 0xFA, 0x43)
Write: [0x60+W] [0x09] [0x00] [0x00, 0x00, 0xFA, 0x43]

// 車輪0の位置目標設定 (1000 counts)
Write: [0x60+W] [0x0B] [0x00] [0xE8, 0x03, 0x00, 0x00]

// 全ステータス読み出し
Write: [0x60+W] [0x30]
Read:  [0x60+R] → 44 bytes

// エンコーダ0 読み出し
Write: [0x60+W] [0x10]
Read:  [0x60+R] → 4 bytes (int32, little-endian)

// 全停止（コースト）
Write: [0x60+W] [0x03]

// デバイスID確認
Write: [0x60+W] [0xFF]
Read:  [0x60+R] → 0x20 0x40
```

---

## USB Serial 通信

**ボーレート**: 115200 bps (USB CDC)

### パケットフォーマット

```
[0xAA][CMD][LEN][DATA x LEN][CHECKSUM]
CHECKSUM = XOR(CMD, LEN, DATA[0], ..., DATA[LEN-1])
```

### コマンド一覧（ホスト → ボード）

| CMD | 値 | データ長 | 内容 |
|---|---|---|---|
| CMD_SET_MOTORS | 0x01 | 8 B | int16 x4 全モータデューティ設定 |
| CMD_STOP_ALL | 0x02 | 0 B | 全停止（コースト、DIRECT モードへ） |
| CMD_BRAKE_ALL | 0x03 | 0 B | 全ブレーキ（DIRECT モードへ） |
| CMD_SET_MOTOR_SINGLE | 0x04 | 3 B | uint8 index + int16 duty |
| CMD_REQUEST_STATUS | 0x10 | 0 B | ステータス1回送信 |
| CMD_RESET_ENCODERS | 0x11 | 0 B | エンコーダリセット |
| CMD_SET_MODE_ALL | 0x20 | 4 B | uint8 x4 制御モード設定 |
| CMD_SET_MODE_SINGLE | 0x21 | 2 B | uint8 index + uint8 mode |
| CMD_SET_VEL_ALL | 0x22 | 16 B | float x4 速度目標 (counts/sec) |
| CMD_SET_VEL_SINGLE | 0x23 | 5 B | uint8 index + float target |
| CMD_SET_POS_ALL | 0x24 | 16 B | int32 x4 位置目標 (counts) |
| CMD_SET_POS_SINGLE | 0x25 | 5 B | uint8 index + int32 target |
| CMD_SET_VEL_PID | 0x26 | 13 B | uint8 index + float kp, ki, kd |
| CMD_SET_POS_GAINS | 0x27 | 9 B | uint8 index + float posKp, maxVelCps |

### レスポンス（ボード → ホスト）

| TYPE | 値 | データ長 | 内容 |
|---|---|---|---|
| RESP_ACK | 0x80 | 1 B | [echo cmd] コマンド受理 |
| RESP_NAK | 0x81 | 1 B | [echo cmd] コマンドエラー |
| RESP_STATUS | 0x91 | 44 B | REG_STATUSと同レイアウト |

ステータスは **100 Hz**（10ms間隔）で自動送信されます。

### シリアル操作例

```python
import struct, serial

ser = serial.Serial('COM3', 115200)

def send_cmd(cmd, data=b''):
    pkt = bytes([0xAA, cmd, len(data)]) + data
    cs = cmd ^ len(data)
    for b in data:
        cs ^= b
    ser.write(pkt + bytes([cs]))

# 速度制御モードに設定（全軸）
send_cmd(0x20, bytes([1, 1, 1, 1]))

# 車輪0の速度目標 500.0 counts/sec
send_cmd(0x23, bytes([0]) + struct.pack('<f', 500.0))

# 全軸位置目標設定 (1000 counts)
send_cmd(0x24, struct.pack('<iiii', 1000, 1000, 1000, 1000))

# 全停止
send_cmd(0x02)
```

---

## ビルド方法

1. [arduino-pico](https://github.com/earlephilhower/arduino-pico) をArduino IDEに追加
   - Board Manager URL: `https://github.com/earlephilhower/arduino-pico/releases/download/global/package_rp2040_index.json`
2. ボード選択: **Raspberry Pi Pico** (または RP2040 互換ボード)
3. `PR2040_MotorDriver.ino` を開いてビルド・書き込み

### 必要ライブラリ

| ライブラリ | 用途 | 入手先 |
|---|---|---|
| Wire (built-in) | I2C通信 | arduino-pico 同梱 |

外部ライブラリの追加は不要です。

---

## エンコーダ仕様

- 直交エンコーダ（A相・B相）をGPIO割り込みで4倍デコード
- 両チャンネルに `CHANGE` 割り込みを設定
- カウント値: `int32_t`（符号付き32bit、オーバーフローまで約21億パルス）
- スレッドセーフ: `getCount()` / `resetCount()` は割り込み禁止区間で保護
- Gray-codeルックアップテーブルによる高速デコード

---

## システム構成

### ハードウェアブロック図

```mermaid
graph TD
    Controller["上位コントローラ\n(Raspberry Pi 等)"]

    subgraph BOARD["PR2040_BASESYSTEM REV1.5.0"]
        subgraph MCU["RP2040 MCU"]
            WC0["WheelController 0\nPID / 位置制御\n200 Hz"]
            WC1["WheelController 1\nPID / 位置制御\n200 Hz"]
            WC2["WheelController 2\nPID / 位置制御\n200 Hz"]
            WC3["WheelController 3\nPID / 位置制御\n200 Hz"]
        end

        TB0["TB67H451\nMotor1\nGPIO8/9"]
        TB1["TB67H451\nMotor2\nGPIO10/11"]
        TB2["TB67H451\nMotor3\nGPIO14/15"]
        TB3["TB67H451\nMotor4\nGPIO16/17"]

        ENC0["Encoder1\nGPIO18/19"]
        ENC1["Encoder2\nGPIO20/21"]
        ENC2["Encoder3\nGPIO22/23"]
        ENC3["Encoder4\nGPIO24/25"]

        MCP["MCP3208\n外部ADC 8ch\nSPI0 100Hz\nGPIO4-7"]
        INA["INA213 ×4\n電流センスアンプ\nGain=50, 10mΩ"]
        IMU["MPU-6881\nIMU 6軸\nI2C0\nGPIO12/13"]
        USB["USB Serial\nCDC 115200bps\nバイナリプロトコル"]
    end

    M0["Motor1"]
    M1["Motor2"]
    M2["Motor3"]
    M3["Motor4"]
    BAT["バッテリ"]

    Controller -->|"I2C スレーブ\naddr=0x60\nGPIO2/3"| MCU

    WC0 -->|PWM| TB0
    WC1 -->|PWM| TB1
    WC2 -->|PWM| TB2
    WC3 -->|PWM| TB3

    TB0 --- M0
    TB1 --- M1
    TB2 --- M2
    TB3 --- M3

    M0 -->|A/B相| ENC0
    M1 -->|A/B相| ENC1
    M2 -->|A/B相| ENC2
    M3 -->|A/B相| ENC3

    ENC0 -->|count| WC0
    ENC1 -->|count| WC1
    ENC2 -->|count| WC2
    ENC3 -->|count| WC3

    M0 -->|電流| INA
    M1 -->|電流| INA
    M2 -->|電流| INA
    M3 -->|電流| INA
    BAT -->|電圧 分圧1/11| MCP
    INA -->|ch0-3| MCP
    MCP -->|SPI| MCU
    IMU -->|I2C| MCU
    MCU <-->|USB CDC| USB
```

### ソフトウェア構成図

```mermaid
graph TD
    subgraph LOOP["loop() メインループ"]
        CTRL["制御ループ\n5ms周期 / 200Hz\nWheelController×4\n.update(dt)"]
        ADCL["外部ADCループ\n10ms周期 / 100Hz\nMCP3208.readAll()\nextAdcBuf更新"]
        STS["ステータス送信\n10ms周期 / 100Hz\nsendStatus()\nUSB Serial"]
    end

    subgraph ISR["割り込みハンドラ (ISR)"]
        I2CR["onI2CReceive()\n書き込み→デファー\n読み出しアドレス設定"]
        I2CS["onI2CRequest()\ni2cReadBuf送信"]
        ENCR["Encoder ISR ×4\nGray-codeデコード\ncount更新"]
    end

    subgraph WC["WheelController 内部構造"]
        ENC_SW["Encoder\nA/B相 4倍デコード\nint32 count"]
        PID_SW["速度PID\nKp/Ki/Kd\n微分 on 測定値\nアンチワインドアップ"]
        MOT_SW["Motor\nTB67H451\nPWM 20kHz\nduty ±1000"]

        ENC_SW -->|"velocity\n(counts/sec)"| PID_SW
        PID_SW -->|duty| MOT_SW
    end

    CTRL -->|update| WC
    ADCL -->|"extAdcBuf[8]"| I2CR
    I2CR -->|pending flag| LOOP
    I2CS -->|"i2cReadBuf"| I2CR
    ENCR -->|count| ENC_SW
```

### 通信シーケンス図

```mermaid
sequenceDiagram
    participant Host as ホスト (PC / Raspberry Pi)
    participant RP2040

    Note over RP2040: 起動完了

    Host->>RP2040: [0xAA][0x20][4][1,1,1,1][cs]<br/>CMD_SET_MODE_ALL: VELOCITY
    RP2040-->>Host: [0xAA][0x80][1][0x20][cs]<br/>RESP_ACK

    Host->>RP2040: [0xAA][0x22][16][f×4][cs]<br/>CMD_SET_VEL_ALL: 500 counts/sec
    RP2040-->>Host: [0xAA][0x80][1][0x22][cs]<br/>RESP_ACK

    loop 100Hz 自動送信
        RP2040-->>Host: [0xAA][0x91][44][enc×4+vel×4+adc×4+ts][cs]<br/>RESP_STATUS
    end

    Host->>RP2040: [0xAA][0x02][0][cs]<br/>CMD_STOP_ALL
    RP2040-->>Host: [0xAA][0x80][1][0x02][cs]<br/>RESP_ACK
```

### 制御モード 状態遷移図

```mermaid
stateDiagram-v2
    [*] --> DIRECT : 起動時デフォルト

    DIRECT --> VELOCITY : CMD_SET_MODE\n(mode=1)
    DIRECT --> POSITION : CMD_SET_MODE\n(mode=2)
    VELOCITY --> DIRECT : CMD_STOP_ALL\nCMD_BRAKE_ALL\nsetDuty()
    VELOCITY --> POSITION : CMD_SET_MODE\n(mode=2)
    POSITION --> DIRECT : CMD_STOP_ALL\nCMD_BRAKE_ALL\nsetDuty()
    POSITION --> VELOCITY : CMD_SET_MODE\n(mode=1)

    state DIRECT {
        [*] --> coast : duty=0
        coast --> running : setDuty(≠0)
        running --> coast : setDuty(0)
    }

    state VELOCITY {
        [*] --> pid_vel : setVelocityTarget()
    }

    state POSITION {
        [*] --> outer_p : setPositionTarget()
        outer_p --> deadband : |error| ≤ 5 counts
        deadband --> outer_p : positionが変化
    }
```

### 制御ループ タイミング図

```mermaid
gantt
    title 制御ループ タイミング (1周期 = 1ms 単位)
    dateFormat x
    axisFormat %Lms

    section 制御ループ (200Hz)
    WheelCtrl update ×4 : 0, 1
    WheelCtrl update ×4 : 5, 1
    WheelCtrl update ×4 : 10, 1
    WheelCtrl update ×4 : 15, 1
    WheelCtrl update ×4 : 20, 1
    WheelCtrl update ×4 : 25, 1

    section 外部ADC (100Hz)
    MCP3208 readAll : 0, 2
    MCP3208 readAll : 10, 2
    MCP3208 readAll : 20, 2

    section ステータス送信 (100Hz)
    sendStatus → USB : 0, 1
    sendStatus → USB : 10, 1
    sendStatus → USB : 20, 1
```

### センサ変換パラメータ

| チャンネル | 物理量 | 変換式 | スケール |
|---|---|---|---|
| ch0-3 | モータ電流 [A] | count × Vref / (4096 × gain × Rshunt) | ~1.611 mA/count |
| ch4 | バッテリ電圧 [V] | count × Vref × (R_upper+R_lower)/R_lower / 4096 | ~8.862 mV/count |

- **Vref** = 3.3V、**ADCフルスケール** = 4096 counts (12bit)
- **INA213**: gain=50 V/V、Rshunt=10 mΩ → 最大計測電流 6.6 A
- **電圧分圧**: R_upper=100 kΩ / R_lower=10 kΩ → 分圧比 1/11 → 最大計測電圧 36.3 V

### I2C 外部ADC・物理値レジスタ（追加）

| レジスタ | アドレス | データ長 | 内容 |
|---|---|---|---|
| REG_EXT_ADC0 | 0x40 | 2 B | int16 MCP3208 ch0 raw (0..4095) |
| REG_EXT_ADC1 | 0x41 | 2 B | int16 MCP3208 ch1 raw |
| REG_EXT_ADC2 | 0x42 | 2 B | int16 MCP3208 ch2 raw |
| REG_EXT_ADC3 | 0x43 | 2 B | int16 MCP3208 ch3 raw |
| REG_EXT_ADC4 | 0x44 | 2 B | int16 MCP3208 ch4 raw |
| REG_EXT_ADC_ALL | 0x48 | 16 B | int16 x8 全チャンネル一括 |
| REG_CURR0 | 0x50 | 4 B | float Motor1電流 [A] |
| REG_CURR1 | 0x51 | 4 B | float Motor2電流 [A] |
| REG_CURR2 | 0x52 | 4 B | float Motor3電流 [A] |
| REG_CURR3 | 0x53 | 4 B | float Motor4電流 [A] |
| REG_VBATT | 0x54 | 4 B | float バッテリ電圧 [V] |

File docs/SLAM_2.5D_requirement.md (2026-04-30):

# SLAM 2.5D システム要件定義書

対象リポジトリ: `/home/pi/MobileRobot`  
対象モジュール: `LiderModule`, `mobile_robot_edge`, `mobile_robot_server`, `edge_services`  
作成目的: ClaudeCode / Codex による実装タスク生成に耐える粒度で、LiderModule を用いた移動ロボット向け SLAM 2.5D システムの要件を定義する。

## 1. 目的

本システムは、移動ロボットに搭載した `LiderModule` の 2D LaserScan とチルト式 3D PointCloud を用いて、室内環境の地図作成、自己位置推定、経路計画、局所障害物回避、段差/穴検出を実現する。

本書でいう **SLAM 2.5D** は、以下の構成を指す。

- グローバル地図と大域経路計画は 2D OccupancyGrid 上で行う。
- LiderModule の水平スライスから `/scan` を生成し、`slam_toolbox` で `/map` と `map -> odom` を生成する。
- LiderModule の下向きチルトスキャンから `/lider/pointcloud2` を生成し、Nav2 local costmap の `voxel_layer`、OctoMap、段差/穴検出へ入力する。
- ロボット制御は既存の `/cmd_vel`、`/odom`、`odom -> base_footprint` を継承する。

点群のみで自己位置推定を行うフル 3D SLAM は対象外とする。初期実装では 2D SLAM を中核に据え、高さ情報は「局所障害物」「床面リスク」「3D 記録」のために使用する。

## 2. 参照すべき既存仕様とコード

実装者は、以下のファイルを優先して参照すること。

| 優先度 | ファイル | 用途 |
|---|---|---|
| 高 | `LiderModule/SPEC.md` | LiderModule のハードウェア、USB CDC プロトコル、座標系、性能値 |
| 高 | `LiderModule/docs/USB_CDC_COMMAND_MANUAL.md` | ホスト実装に必要なバイナリフレーム仕様 |
| 高 | `LiderModule/firmware/lidar_tilt_3d/lidar_tilt_3d.ino` | ESP32-S3 ファームウェアの実動作 |
| 高 | `LiderModule/host/rpi_tilt_3d.py` | USB CDC パース、点群再構成、PLY/CSV 保存の参照実装 |
| 高 | `LiderModule/host/downward_hazard_monitor.py` | 段差/穴検出の参照実装 |
| 高 | `mobile_robot_edge/mobile_robot_edge/lider_module_node.py` | ROS 2 Topic 化の現行実装 |
| 高 | `mobile_robot_edge/launch/ws_edge_bringup.launch.py` | edge 側 bringup、TF、LiderModule 起動設定 |
| 高 | `edge_services/config/robot_config.json` | wheel odometry、motor service、WebSocket、USB ポート設定 |
| 高 | `mobile_robot_server/config/slam_toolbox_params.yaml` | 既存 2D SLAM 設定 |
| 高 | `mobile_robot_server/config/nav2_params.yaml` | 既存 Nav2 設定 |
| 高 | `mobile_robot_server/launch/server_bringup.launch.py` | サーバ側 bringup と Nav2 lifecycle 構成 |

## 3. 現行システムの前提

### 3.1 LiderModule

`LiderModule` は、YDLIDAR T-mini Pro を FEETECH STS3215 サーボでチルトさせ、XIAO ESP32-S3 が LiDAR、サーボ角、MPU6050 DMP 姿勢を USB CDC バイナリプロトコルで Raspberry Pi へ送信するモジュールである。

主要仕様:

| 項目 | 現行値 |
|---|---|
| LiDAR | YDLIDAR T-mini Pro |
| LiDAR range | 0.02 m から 12.0 m |
| LiDAR 回転 | 約 6 Hz |
| LiDAR UART | 230400 bps |
| チルトサーボ | STS3215, ID 1, center 2048 |
| チルト範囲 | 運用上 -45 deg から +45 deg、保護上限 -50 deg から +50 deg |
| IMU | MPU6050 DMP、pitch/roll/yaw を送信、yaw は相対方位 |
| USB CDC | 921600 bps 設定、DTR/RTS false 推奨 |
| フレーム同期 | `[0xFE][0xEF][TYPE][LEN_L][LEN_H][PAYLOAD][CHECKSUM]` |

### 3.2 ROS 2 edge 側

`mobile_robot_edge/mobile_robot_edge/lider_module_node.py` は現状で以下を発行する。

| Topic | 型 | 用途 | 現行周期 |
|---|---|---|---|
| `/scan` | `sensor_msgs/msg/LaserScan` | 2D SLAM、障害物 layer | 約 5 から 6 Hz |
| `/lider/pointcloud2` | `sensor_msgs/msg/PointCloud2` | 3D 障害物、OctoMap、床面リスク | 既定 30 秒周期 |
| `/lider/imu` | `sensor_msgs/msg/Imu` | 姿勢情報の将来利用 | IMU 受信時、約 50 Hz |

ただし、`/lider/imu` の現行 ROS メッセージは orientation quaternion、angular velocity、linear acceleration を未充填とし、covariance で unknown を示している。したがって、初期実装では robot_localization の融合入力として使わない。

### 3.3 走行系

`edge_services/config/robot_config.json` と `mobile_robot_edge` の WebSocket bridge により、以下のインターフェースが存在する。

| Topic / Service | 役割 |
|---|---|
| `/odom` | wheel odometry |
| `odom -> base_footprint` | wheel odometry TF |
| `/cmd_vel` | Nav2 から motor service への速度指令 |
| `ws_motor_controller` | `/cmd_vel` を motor service へ転送 |
| `ws_odometry_publisher` | odometry service から `/odom` と TF を発行 |

現行 `robot_config.json` では motor、odometry、hardware がいずれも `/dev/ttyACM0` を使う設定になっている。LiderModule も launch 上で `/dev/ttyACM0` を使うため、このままでは USB ポート競合が起きる。

### 3.4 server 側

`mobile_robot_server` には、`slam_toolbox`、Nav2、collision monitor、velocity smoother、LLM navigation などの構成が存在する。既存の `nav2_params.yaml` は `/scan` を obstacle source として扱うが、`/lider/pointcloud2` を用いた voxel layer はまだ定義されていない。

## 4. システム全体構成

```mermaid
flowchart LR
    subgraph HW["Robot Hardware"]
        LM["LiderModule\nYDLIDAR + STS3215 + MPU6050 + ESP32-S3"]
        MC["PR2040 Motor Driver\nMotors + Encoders"]
        PI["Raspberry Pi"]
    end

    LM -- "USB CDC /dev/lider_module" --> PI
    MC -- "USB Serial /dev/pr2040" --> PI

    subgraph EDGE["ROS 2 Edge"]
        LNODE["lider_module_node\n/scan\n/lider/pointcloud2\n/lider/imu"]
        ODOM["ws_odometry_publisher\n/odom\nodom->base_footprint"]
        MOTOR["ws_motor_controller\n/cmd_vel"]
        RSP["robot_state_publisher\nURDF/Xacro"]
    end

    subgraph SLAMNAV["SLAM 2.5D"]
        SLAM["slam_toolbox\n/map\nmap->odom"]
        NAV2["Nav2\nGlobal/Local Costmap"]
        VOX["Voxel Layer\nPointCloud2 obstacle"]
        OCTO["octomap_server\n3D map"]
        HAZ["downward_hazard_node\nSTEP_DOWN / HOLE"]
        SAFE["collision_monitor\nwatchdog / emergency stop"]
    end

    PI --> LNODE
    PI --> ODOM
    PI --> MOTOR
    PI --> RSP

    LNODE --> SLAM
    ODOM --> SLAM
    RSP --> SLAM
    SLAM --> NAV2
    ODOM --> NAV2
    RSP --> NAV2
    LNODE --> VOX
    VOX --> NAV2
    LNODE --> OCTO
    LNODE --> HAZ
    LNODE --> SAFE
    NAV2 --> MOTOR
```

## 5. 機能要件

### F-01 LiderModule ROS 2 ドライバ

`lider_module_node` は、USB CDC から LiderModule バイナリフレームを読み取り、ROS 2 標準メッセージへ変換する。

必須要件:

- 起動パラメータ `port` の既定を `/dev/lider_module` に変更できること。
- baudrate は `921600` を使用すること。
- serial open 後に DTR/RTS を false にすること。
- `0x02` IMU、`0x04` ScanSlice、`0x05` ScanStatus を受信できること。
- `0x10` Servo Angle、`0x12` Scan Start、`0x13` Scan Stop を送信できること。
- 受信処理は専用 thread で非ブロッキングに行うこと。
- shutdown 時は `CMD_SCAN_STOP` と `CMD_SERVO_ANGLE(0.0)` を送信すること。

実装修正要求:

- `LiderModule/docs/USB_CDC_COMMAND_MANUAL.md` の拡張 ScanSlice header `22 + count * 5` を正式にサポートすること。
- 旧形式 `14 + count * 5` も互換サポートし、旧形式では `tilt_start = tilt_end = tilt_deg` として扱うこと。
- 拡張形式では点ごとのチルト角を `tilt_start_deg -> tilt_end_deg` で線形補間し、サーボ移動中の螺旋スキャンとして 3D 座標へ変換すること。
- `ScanSlice` dataclass は `tilt_deg`, `tilt_start_deg`, `tilt_end_deg`, `imu_pitch`, `imu_roll`, `points` を持つこと。
- quality filter のパラメータ `min_quality` を追加し、既定値は `0` とすること。

### F-02 `/scan` 生成

`/scan` は `LaserScan` として発行し、2D SLAM と Nav2 obstacle layer の入力とする。

必須要件:

- frame_id は `laser_frame` とする。
- angle range は `-pi` から `+pi` とする。
- bins は既定 `720` とし、約 0.5 deg 分解能を維持する。
- range_min は `0.02`、range_max は `12.0` を既定とする。
- range 外の値は `inf` とする。
- 同一 bin に複数点が入る場合、最短距離を採用する。
- scan_time は T-mini Pro の実測に合わせて既定 `1.0 / 6.0` とする。
- Nav2 で chassis 反射を避けるため、costmap 側では `obstacle_min_range` を `0.15` 以上に設定する。

受入基準:

- `ros2 topic hz /scan` が 5 Hz 以上を 10 分間維持する。
- `ros2 topic echo /scan --once` で frame_id、range_min、range_max、ranges が妥当である。
- RViz で水平スキャンが `laser_frame` に表示される。

### F-03 `/lider/pointcloud2` 生成

`/lider/pointcloud2` は `PointCloud2` として発行し、3D 障害物、床面リスク、OctoMap の入力とする。

必須要件:

- frame_id は `laser_frame` とする。
- fields は最低限 `x`, `y`, `z` の `float32` とする。
- 単位は meter とする。
- 座標系は `X: 前方`, `Y: 左方`, `Z: 上方` とする。
- `tilt_axis_offset_m` を反映すること。
- IMU pitch/roll による姿勢補正を適用できること。
- `pointcloud_interval_s` は 0 で無効化、正の値で周期実行とする。
- 実運用既定値は `2.0` 秒とする。現行の `30.0` 秒はデバッグ用途とする。
- 1 回の pointcloud 生成に使用する下向き角度列は、既存 `DOWN_ANGLES` を初期値として維持する。

受入基準:

- `ros2 topic hz /lider/pointcloud2` が設定周期に従う。
- RViz で下向き点群が `laser_frame` 基準に表示される。
- `pointcloud_interval_s:=2.0` で 10 分間、ノードが timeout 連発せず動作する。

### F-04 `/lider/imu` 生成

`/lider/imu` は `sensor_msgs/msg/Imu` として発行する。

初期必須要件:

- frame_id は `imu_link` とする。
- 現行 firmware から受信する pitch/roll/yaw はログまたは diagnostic 用に保持する。
- orientation quaternion が未計算の場合、orientation covariance の先頭を `-1.0` とし、融合不可を明示する。
- angular velocity と linear acceleration が未提供の場合、それぞれ covariance の先頭を `-1.0` とする。

拡張要件:

- robot_localization へ入力する場合、pitch/roll/yaw から quaternion を生成し、yaw が相対方位である制約を明記する。
- angular velocity と linear acceleration を使う場合は firmware 側 payload 拡張を別タスクとする。

### F-05 TF / URDF

TF tree は以下を満たす。

```text
map -> odom -> base_footprint -> base_link -> laser_frame -> imu_link
                                      |
                                      -> camera_optical_frame
```

必須要件:

- `map -> odom` は `slam_toolbox` が発行する。
- `odom -> base_footprint` は `ws_odometry_publisher` が発行する。
- `base_footprint -> base_link -> laser_frame -> imu_link` は `robot_state_publisher` が URDF/Xacro から発行する。
- launch 内 inline URDF は廃止し、`mobile_robot_edge/urdf/mobile_robot.urdf.xacro` または共通 package の URDF へ外出しする。
- `laser_frame` の位置は現行仮値 `(x=0.05, y=0.0, z=0.08)` から、実機計測値へ更新可能な xacro property とする。
- `base_footprint -> base_link` の z は現行仮値 `0.033` を初期値とし、実測可能にする。

受入基準:

- `ros2 run tf2_tools view_frames` で tree が一意につながる。
- `ros2 run tf2_ros tf2_echo map laser_frame` が SLAM 起動後に解決できる。
- RViz fixed frame `map` で robot model、scan、pointcloud が同時表示できる。

### F-06 2D SLAM

2D SLAM は `slam_toolbox` を標準実装とする。

必須要件:

- 入力 topic は `/scan` と `/odom` と `/tf` とする。
- 出力 topic は `/map` とし、`map -> odom` TF を発行する。
- 既存 `mobile_robot_server/config/slam_toolbox_params.yaml` を基準に、LiderModule 用として維持する。
- map resolution は `0.05` m/cell を既定とする。
- `base_frame` は `base_footprint` とする。
- `max_laser_range` は `12.0` とする。
- map save の手順を launch または README に定義する。

受入基準:

- 5 m 四方以上の室内走行で `/map` が生成される。
- `map -> odom` が 20 Hz 以上で発行される。
- 保存した map を Nav2 global costmap に読み込める。

### F-07 Nav2 2.5D costmap

Nav2 は 2D global costmap と 2.5D local costmap を持つ。

global costmap 要件:

- `global_frame` は `map`。
- `robot_base_frame` は `base_footprint`。
- `static_layer` は `/map` を購読する。
- `inflation_layer` を有効化する。
- resolution は `0.05` m/cell。

local costmap 要件:

- `global_frame` は `odom`。
- `robot_base_frame` は `base_footprint`。
- rolling window を有効化する。
- 初期 width/height は `3.0` m 以上、推奨 `4.0` から `6.0` m。
- `obstacle_layer` は `/scan` を `LaserScan` として購読する。
- `voxel_layer` は `/lider/pointcloud2` を `PointCloud2` として購読する。
- `inflation_layer` を有効化する。
- `obstacle_min_range` は `0.15` m 以上とし、ロボット自身の反射を除外する。
- `max_obstacle_height` は初期値 `1.5` m とする。
- `z_resolution` は `0.05` m、`z_voxels` は初期値 `16` とする。

受入基準:

- `/scan` の障害物が local costmap に反映される。
- `/lider/pointcloud2` の立体障害物が local costmap の voxel layer に反映される。
- Nav2 が `/cmd_vel` を出力し、`ws_motor_controller` 経由で走行系へ届く。

### F-08 OctoMap

OctoMap は 3D 記録と可視化のために導入する。Nav2 の必須経路計画には使わない。

必須要件:

- 入力は `/lider/pointcloud2` とする。
- frame は TF で `map` または `odom` へ変換可能であること。
- octomap resolution は初期値 `0.05` m とする。
- `.bt` または `.ot` 形式で保存できること。
- CPU 負荷が高い場合は更新周期または resolution を落とせること。

受入基準:

- 1 分以上の走行後、OctoMap を保存できる。
- RViz または外部 viewer で 3D map を確認できる。

### F-09 段差/穴検出

段差/穴検出は `LiderModule/host/downward_hazard_monitor.py` の考え方を ROS 2 node 化する。

新規 node 名:

- `downward_hazard_node`

入力:

- `/lider/pointcloud2`
- `/tf`

出力:

| Topic | 型 | 内容 |
|---|---|---|
| `/hazard/downward_status` | `std_msgs/msg/String` | `SAFE`, `STEP_DOWN`, `HOLE`, `UNKNOWN` |
| `/hazard/downward_debug` | `diagnostic_msgs/msg/DiagnosticArray` | 閾値、点数、理由 |
| `/hazard/downward_stop` | `std_msgs/msg/Bool` | 走行停止要求 |

必須要件:

- forward lane ROI を `X` と `Y` の範囲で設定できること。
- 近傍床面 ROI から reference ground z を percentile で推定すること。
- x 方向 bin ごとの床面 profile を作ること。
- 急な負方向 z 変化を `STEP_DOWN` と判定すること。
- sparse bin または reference から深い z を `HOLE` と判定すること。
- 点数不足時は `UNKNOWN` とすること。
- パラメータは YAML 化すること。

初期パラメータ:

| パラメータ | 初期値 |
|---|---:|
| `eval_x_min` | 0.15 |
| `eval_x_max` | 1.20 |
| `eval_y_half` | 0.20 |
| `bin_size` | 0.05 |
| `step_drop_m` | 0.08 |
| `hole_depth_m` | 0.10 |
| `min_points_for_eval` | 200 |
| `min_points_per_bin` | 3 |

受入基準:

- 平坦床で `SAFE` を出す。
- 0.10 m 以上の下り段差で `STEP_DOWN` または `HOLE` を出す。
- 点群欠落時に `UNKNOWN` を出し、必要に応じて停止要求を出す。

### F-10 安全停止

安全停止は多層で実装する。

必須要件:

- hardware emergency stop を設け、モータ電源を物理的に遮断できること。
- `edge_services` の `cmd_vel_timeout` を維持し、無通信時に停止すること。
- Nav2 `collision_monitor` を lifecycle 管理対象に含めること。
- `collision_monitor` は `/scan` を監視し、前方停止 polygon で停止できること。
- `downward_hazard_node` が危険を出した場合、Nav2 を介さず停止指令を出せる構成を用意すること。
- LiderModule node が serial disconnected を検知した場合、diagnostic と停止要求を出せること。

受入基準:

- `/cmd_vel` が途絶えた場合、0.5 秒以内に motor service が停止する。
- 前方停止 polygon 内に障害物を置いた場合、ロボットが停止する。
- `/lider/pointcloud2` 欠落または LiderModule 切断時に安全側へ倒れる。

## 6. 非機能要件

### 6.1 実行環境

| 項目 | 要件 |
|---|---|
| ROS 2 | Jazzy Jalisco に統一 |
| OS | Ubuntu 24.04 arm64 推奨。Docker 実行も可 |
| SBC | Raspberry Pi 5 8GB 推奨、Raspberry Pi 4 4GB は縮退運用 |
| Python | ROS 2 Jazzy 標準 Python |
| 依存 | `pyserial`, `numpy`, `websockets`, Nav2, slam_toolbox, robot_state_publisher, octomap_server |

### 6.2 性能

| 項目 | 要件 |
|---|---|
| `/scan` | 5 Hz 以上 |
| `/odom` | 50 Hz 維持 |
| `/lider/imu` | 50 Hz 目標 |
| `/lider/pointcloud2` | 実運用 0.2 から 1.0 Hz、初期値 0.5 Hz |
| local costmap update | 5 Hz 目標 |
| global costmap update | 1 Hz 目標 |
| 停止レイテンシ | 300 ms 目標、500 ms 上限 |
| 連続稼働 | 最低 30 分 |

### 6.3 信頼性

- USB ポート名は udev で固定する。
- `/dev/ttyACM0` を直接本番設定に書かない。
- `lider_module_node`、WebSocket bridge、Nav2 lifecycle node は respawn または lifecycle で復旧可能にする。
- sensor timeout を diagnostic に出す。
- rosbag2 で `/scan`, `/lider/pointcloud2`, `/lider/imu`, `/odom`, `/tf`, `/cmd_vel`, `/map` を記録できること。

### 6.4 セキュリティ

- 単機運用時、`edge_services` の host は `127.0.0.1` を既定とする。
- 外部 PC へ公開する場合のみ `0.0.0.0` を明示的に使う。
- Docker 本番運用では `privileged: true` と `network_mode: host` の利用を再評価し、必要最小権限にする。

## 7. インターフェース仕様

### 7.1 ROS Topics

| Topic | 型 | Publisher | Subscriber | 必須 |
|---|---|---|---|---|
| `/scan` | `sensor_msgs/msg/LaserScan` | `lider_module_node` | `slam_toolbox`, Nav2, collision monitor | 必須 |
| `/lider/pointcloud2` | `sensor_msgs/msg/PointCloud2` | `lider_module_node` | voxel layer, OctoMap, hazard node | 必須 |
| `/lider/imu` | `sensor_msgs/msg/Imu` | `lider_module_node` | diagnostics, future EKF | 必須 |
| `/odom` | `nav_msgs/msg/Odometry` | `ws_odometry_publisher` | SLAM, Nav2 | 必須 |
| `/cmd_vel` | `geometry_msgs/msg/Twist` | Nav2 / safety | `ws_motor_controller` | 必須 |
| `/map` | `nav_msgs/msg/OccupancyGrid` | `slam_toolbox` | Nav2 global costmap | 必須 |
| `/tf` | `tf2_msgs/msg/TFMessage` | SLAM, odom, RSP | all | 必須 |
| `/tf_static` | `tf2_msgs/msg/TFMessage` | RSP | all | 必須 |
| `/octomap_binary` | `octomap_msgs/msg/Octomap` | `octomap_server` | RViz / saver | 任意 |
| `/hazard/downward_status` | `std_msgs/msg/String` | `downward_hazard_node` | safety / UI | 必須 |
| `/hazard/downward_stop` | `std_msgs/msg/Bool` | `downward_hazard_node` | safety mux | 必須 |

### 7.2 USB CDC messages

LiderModule USB CDC は以下を必須サポートとする。

| Direction | Type | 名称 | Payload |
|---|---:|---|---|
| ESP32 -> RPi | `0x02` | IMU data | `pitch_f32, roll_f32, yaw_f32` |
| ESP32 -> RPi | `0x04` | 3D scan slice | 拡張 header 22 byte + points |
| ESP32 -> RPi | `0x05` | scan status | `state_u8, step_u16, total_u16` |
| RPi -> ESP32 | `0x10` | servo angle | `angle_deg_f32` |
| RPi -> ESP32 | `0x12` | scan start | `tilt_min_f32, tilt_max_f32, tilt_step_f32` |
| RPi -> ESP32 | `0x13` | scan stop | empty |

### 7.3 設定ファイル

新規または修正対象の設定ファイル:

```text
mobile_robot_edge/
  config/
    lider_module.yaml
    edge_bridge.yaml
    hazard_downward.yaml
  launch/
    sensors.launch.py
    edge_25d_bringup.launch.py
  urdf/
    mobile_robot.urdf.xacro

mobile_robot_server/
  config/
    slam_toolbox_params.yaml
    nav2_25d_params.yaml
    octomap_params.yaml
  launch/
    slam_25d.launch.py
    nav2_25d.launch.py
    octomap.launch.py
    server_25d_bringup.launch.py

scripts/
  install_udev_rules.sh
  99-mobilerobot.rules
```

## 8. 実装タスク定義

ClaudeCode / Codex へ依頼する際は、以下の単位で分割する。

### T-01 USB CDC parser の拡張

対象:

- `mobile_robot_edge/mobile_robot_edge/lider_module_node.py`
- unit test

要件:

- 拡張 ScanSlice header 22 byte を parse する。
- 旧 header 14 byte を parse する。
- checksum 不一致、payload 長不足、count と実 payload 不一致を安全に破棄する。
- `tilt_start_deg`, `tilt_end_deg` を pointcloud 変換へ反映する。

完了条件:

- `python -m pytest` または `colcon test` で parser test が通る。
- 既存旧形式の fixture と新形式の fixture の両方が通る。

### T-02 LiderModule パラメータ YAML 化

対象:

- `mobile_robot_edge/config/lider_module.yaml`
- `mobile_robot_edge/launch/sensors.launch.py`

要件:

- launch 内の LiderModule パラメータ直書きを廃止する。
- port 既定を `/dev/lider_module` にする。
- `pointcloud_interval_s` 既定を `2.0` にする。
- `min_quality` を追加する。

完了条件:

- `ros2 launch mobile_robot_edge sensors.launch.py` で node が起動する。

### T-03 URDF/Xacro 化

対象:

- `mobile_robot_edge/urdf/mobile_robot.urdf.xacro`
- `mobile_robot_edge/launch/sensors.launch.py`
- `mobile_robot_server/launch/server_25d_bringup.launch.py`

要件:

- inline URDF を廃止する。
- `base_footprint`, `base_link`, `laser_frame`, `imu_link`, `camera_optical_frame` を定義する。
- xacro property で robot size、laser pose、camera pose を調整可能にする。

完了条件:

- `robot_state_publisher` が xacro 由来の robot_description で起動する。
- TF tree が一意に接続される。

### T-04 udev 固定デバイス名

対象:

- `scripts/99-mobilerobot.rules`
- `scripts/install_udev_rules.sh`
- README または setup doc

要件:

- LiderModule を `/dev/lider_module` に固定する。
- PR2040 motor driver を `/dev/pr2040` に固定する。
- VID/PID が同一で区別不能な場合は serial attribute または physical path を使う。
- `robot_config.json` と LiderModule launch から `/dev/ttyACM0` 直指定を排除する。

完了条件:

- USB 抜き差し後も symlink が維持される。

### T-05 Nav2 2.5D params

対象:

- `mobile_robot_server/config/nav2_25d_params.yaml`
- `mobile_robot_server/launch/nav2_25d.launch.py`

要件:

- 既存 Nav2 設定を複製せず、必要に応じて 2.5D 用ファイルへ整理する。
- local costmap に `obstacle_layer`, `voxel_layer`, `inflation_layer` を定義する。
- `voxel_layer` の observation source に `/lider/pointcloud2` を設定する。
- `collision_monitor` を lifecycle 管理対象へ含める。

完了条件:

- Nav2 lifecycle nodes が active になる。
- `/scan` と `/lider/pointcloud2` が local costmap に反映される。

### T-06 OctoMap 統合

対象:

- `mobile_robot_server/config/octomap_params.yaml`
- `mobile_robot_server/launch/octomap.launch.py`

要件:

- `/lider/pointcloud2` から OctoMap を構築する。
- resolution、max_range、frame_id を YAML 化する。
- 保存コマンドを README に記載する。

完了条件:

- `.bt` または `.ot` ファイル保存に成功する。

### T-07 downward_hazard_node

対象:

- `mobile_robot_edge/mobile_robot_edge/downward_hazard_node.py`
- `mobile_robot_edge/config/hazard_downward.yaml`
- tests

要件:

- `downward_hazard_monitor.py` の `compute_hazard()` を ROS node 化する。
- PointCloud2 を numpy 配列に変換する。
- `SAFE`, `STEP_DOWN`, `HOLE`, `UNKNOWN` を publish する。
- 危険時に `/hazard/downward_stop` を true にする。

完了条件:

- unit test で平坦床、段差、穴、点数不足を判定できる。

### T-08 rosbag2 記録と再生

対象:

- `scripts/record_25d_bag.sh`
- `scripts/play_25d_bag.sh`

記録 topic:

```bash
/scan
/lider/pointcloud2
/lider/imu
/odom
/tf
/tf_static
/cmd_vel
/map
/hazard/downward_status
```

完了条件:

- 実機なしでも rosbag replay で SLAM / hazard / costmap の回帰確認ができる。

## 9. 受入試験

### 9.1 単体試験

| 試験 | 条件 | 合格基準 |
|---|---|---|
| USB frame checksum | 正常/異常 frame | 正常のみ decode |
| ScanSlice 旧形式 | 14 byte header | `tilt_start == tilt_end == tilt` |
| ScanSlice 新形式 | 22 byte header | tilt 補間が有効 |
| LaserScan binning | 同一 bin 複数点 | 最短距離を採用 |
| PointCloud transform | 既知角度/距離 | 期待座標との差が 1 cm 以下 |
| Hazard flat | 平坦点群 | `SAFE` |
| Hazard step | 下り段差点群 | `STEP_DOWN` |
| Hazard hole | 欠落/深い床面 | `HOLE` |

### 9.2 統合試験

| 試験 | 条件 | 合格基準 |
|---|---|---|
| Edge bringup | LiderModule + motor driver 接続 | `/scan`, `/odom`, TF が出る |
| SLAM bringup | `/scan` + `/odom` | `/map`, `map->odom` が出る |
| Nav2 bringup | map あり | lifecycle nodes active |
| Voxel layer | `/lider/pointcloud2` 入力 | local costmap に反映 |
| Collision monitor | 前方障害物 | `/cmd_vel` が停止方向へ制限 |
| Hazard stop | 段差/穴点群 | `/hazard/downward_stop=true` |
| Device disconnect | LiderModule USB 抜去 | diagnostic と停止要求 |

### 9.3 実機フィールド試験

| 指標 | 合格基準 |
|---|---|
| 連続稼働 | 30 分以上、主要 node crash なし |
| 地図作成 | 5 m 四方以上の室内で map 保存成功 |
| ゴール到達 | 10 回中 8 回以上成功 |
| 障害物停止 | 前方 0.3 m から 0.5 m の障害物で停止 |
| 段差/穴検出 | 0.10 m 以上の段差/穴で 90% 以上検出 |
| CPU | Pi 5 で平均 80% 未満を目標 |
| メモリ | swap 多用なし |

## 10. 未解決事項

実装前または実装中に確認すること。

| 項目 | 状態 | 対応 |
|---|---|---|
| wheel_base / encoder_cpr | README と `robot_config.json` に差異あり | 実測し、単一設定へ統一 |
| LiderModule VID/PID | 未確認 | `udevadm info` で取得 |
| PR2040 VID/PID | 未確認 | `udevadm info` で取得 |
| `/lider/imu` の融合可否 | 現行では融合不可 | quaternion 化または payload 拡張を別タスク |
| ScanSlice 拡張形式 | SPEC と node 実装に差分あり | T-01 で修正 |
| Pi 4 負荷 | 未検証 | Pi 5 を基準、Pi 4 は interval/resolution を下げる |
| OctoMap 実行ファイル名 | 環境差あり | `ros2 pkg executables octomap_server` で確認 |

## 11. 初期 YAML 例

### 11.1 `mobile_robot_edge/config/lider_module.yaml`

```yaml
lider_module_node:
  ros__parameters:
    port: /dev/lider_module
    baudrate: 921600
    scan_frame_id: laser_frame
    imu_frame_id: imu_link
    min_range_m: 0.02
    max_range_m: 12.0
    laser_scan_bins: 720
    slice_timeout_s: 4.0
    pointcloud_interval_s: 2.0
    tilt_axis_offset_m: 0.023
    min_quality: 0
```

### 11.2 `mobile_robot_server/config/nav2_25d_params.yaml` の local costmap 抜粋

```yaml
local_costmap:
  local_costmap:
    ros__parameters:
      use_sim_time: false
      update_frequency: 5.0
      publish_frequency: 2.0
      global_frame: odom
      robot_base_frame: base_footprint
      rolling_window: true
      width: 4.0
      height: 4.0
      resolution: 0.05
      robot_radius: 0.15
      plugins: ["obstacle_layer", "voxel_layer", "inflation_layer"]

      obstacle_layer:
        plugin: "nav2_costmap_2d::ObstacleLayer"
        enabled: true
        observation_sources: scan
        scan:
          topic: /scan
          data_type: "LaserScan"
          marking: true
          clearing: true
          obstacle_min_range: 0.15
          obstacle_max_range: 4.0
          raytrace_min_range: 0.15
          raytrace_max_range: 5.0

      voxel_layer:
        plugin: "nav2_costmap_2d::VoxelLayer"
        enabled: true
        publish_voxel_map: true
        origin_z: 0.0
        z_resolution: 0.05
        z_voxels: 16
        max_obstacle_height: 1.5
        observation_sources: lider_points
        lider_points:
          topic: /lider/pointcloud2
          data_type: "PointCloud2"
          marking: true
          clearing: true
          obstacle_min_range: 0.15
          obstacle_max_range: 3.0
          raytrace_min_range: 0.15
          raytrace_max_range: 4.0

      inflation_layer:
        plugin: "nav2_costmap_2d::InflationLayer"
        inflation_radius: 0.35
        cost_scaling_factor: 3.0
```

### 11.3 `mobile_robot_edge/config/hazard_downward.yaml`

```yaml
downward_hazard_node:
  ros__parameters:
    pointcloud_topic: /lider/pointcloud2
    status_topic: /hazard/downward_status
    stop_topic: /hazard/downward_stop
    target_frame: base_footprint
    ref_x_min: 0.05
    ref_x_max: 0.30
    ref_y_half: 0.15
    eval_x_min: 0.15
    eval_x_max: 1.20
    eval_y_half: 0.20
    bin_size: 0.05
    ref_percentile: 30.0
    bin_percentile: 25.0
    step_drop_m: 0.08
    hole_depth_m: 0.10
    min_points_for_eval: 200
    min_ref_points: 20
    min_lane_points: 80
    min_points_per_bin: 3
    min_step_events: 1
    min_hole_bins: 2
    fail_safe_on_unknown: true
```

## 12. 実装完了の定義

本要件は、以下をすべて満たした時点で完了とする。

- `/dev/lider_module` と `/dev/pr2040` が固定され、ポート競合がない。
- `lider_module_node` が拡張 ScanSlice 形式を正しく扱う。
- `/scan`, `/lider/pointcloud2`, `/lider/imu`, `/odom`, TF が同時に出る。
- `slam_toolbox` により `/map` と `map -> odom` が生成される。
- Nav2 が 2D map 上で経路計画し、local costmap が `/scan` と `/lider/pointcloud2` を反映する。
- OctoMap を保存できる。
- downward hazard が `SAFE`, `STEP_DOWN`, `HOLE`, `UNKNOWN` を出せる。
- collision monitor と watchdog により安全停止できる。
- rosbag2 で主要 topic を記録し、再生テストできる。
- 単体試験、統合試験、実機フィールド試験の合格基準を満たす。

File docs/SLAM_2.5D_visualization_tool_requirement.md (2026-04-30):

# SLAM 2.5D 可視化ツール要件定義書

対象リポジトリ: `/home/pi/MobileRobot`  
関連要件: `docs/SLAM_2.5D_requirement.md`  
対象方式: Step1 は **RViz2 ベース可視化**、将来拡張として **Web ダッシュボード**を定義する。

## 1. 目的

本ツールは、SLAM 2.5D システムの 2D Map、OctoMap、LiderModule 点群、LaserScan、TF、ロボット姿勢、Nav2 costmap、段差/穴検出状態を同一座標系で確認できる可視化環境を提供する。

Step1 では ROS 2 標準ツールである RViz2 を用い、開発・調整・実機試験・rosbag 再生確認に使える再現性の高い可視化プリセットを作成する。Web ダッシュボードは、運用者向けの軽量監視 UI として将来拡張扱いにする。

## 2. スコープ

### 2.1 Step1 対象

- RViz2 設定ファイルの作成
- RViz2 起動 launch の作成
- 2D Map と OctoMap の同時可視化
- `/scan`, `/lider/pointcloud2`, `/odom`, TF, RobotModel, Nav2 costmap の可視化
- hazard 状態を確認するための topic 表示
- 実機起動時と rosbag replay 時の両方で利用できる構成

### 2.2 将来拡張対象

- ブラウザで閲覧できる Web ダッシュボード
- 2D map の Canvas 表示
- 点群または OctoMap の Three.js 表示
- Topic health、hazard status、Nav2 状態の監視
- タブレットまたは別 PC からの軽量閲覧

### 2.3 対象外

- Step1 での独自 3D レンダリングエンジン実装
- Step1 での地図編集機能
- Step1 での経路指示 UI
- Step1 での OctoMap 解析アルゴリズム実装
- Web ダッシュボードからのロボット操作

## 3. 参照する既存ファイル

| ファイル | 用途 |
|---|---|
| `docs/SLAM_2.5D_requirement.md` | SLAM 2.5D 全体要件 |
| `mobile_robot_server/launch/server_bringup.launch.py` | SLAM / Nav2 / collision monitor 起動構成 |
| `mobile_robot_server/config/slam_toolbox_params.yaml` | `/map` と `map -> odom` の前提 |
| `mobile_robot_server/config/nav2_params.yaml` | Nav2 costmap / collision monitor の前提 |
| `mobile_robot_edge/mobile_robot_edge/lider_module_node.py` | `/scan`, `/lider/pointcloud2`, `/lider/imu` の topic 仕様 |
| `mobile_robot_edge/launch/ws_edge_bringup.launch.py` | edge 側 TF とセンサ起動構成 |

## 4. 可視化対象

Step1 の RViz2 では、以下を表示対象とする。

| 表示名 | Topic / Frame | 型 | 必須 | 用途 |
|---|---|---|---|---|
| TF | `/tf`, `/tf_static` | `tf2_msgs/msg/TFMessage` | 必須 | frame 接続確認 |
| RobotModel | `robot_description` | URDF | 必須 | ロボット姿勢確認 |
| 2D Map | `/map` | `nav_msgs/msg/OccupancyGrid` | 必須 | SLAM map 確認 |
| LaserScan | `/scan` | `sensor_msgs/msg/LaserScan` | 必須 | 水平 LiDAR 確認 |
| Lider PointCloud | `/lider/pointcloud2` | `sensor_msgs/msg/PointCloud2` | 必須 | 2.5D 点群確認 |
| Odometry | `/odom` | `nav_msgs/msg/Odometry` | 必須 | wheel odometry 確認 |
| Global Plan | `/plan` | `nav_msgs/msg/Path` | 推奨 | Nav2 経路確認 |
| Local Plan | controller 出力 path | `nav_msgs/msg/Path` | 任意 | controller 確認 |
| Global Costmap | `/global_costmap/costmap` | `nav_msgs/msg/OccupancyGrid` | 推奨 | 大域 costmap 確認 |
| Local Costmap | `/local_costmap/costmap` | `nav_msgs/msg/OccupancyGrid` | 推奨 | 局所 costmap 確認 |
| Voxel Markers | voxel layer 出力 | 環境依存 | 任意 | voxel layer 確認 |
| OctoMap | `/octomap_binary` または `/octomap_full` | `octomap_msgs/msg/Octomap` | 必須 | 3D 地図確認 |
| Hazard Status | `/hazard/downward_status` | `std_msgs/msg/String` | 推奨 | 段差/穴状態確認 |
| Cmd Vel | `/cmd_vel` | `geometry_msgs/msg/Twist` | 推奨 | 制御出力確認 |

## 5. RViz2 機能要件

### V-01 RViz2 プリセット

RViz2 設定ファイルを作成する。

成果物:

```text
mobile_robot_server/config/rviz/slam_25d.rviz
```

必須要件:

- Fixed Frame は `map` を既定とする。
- `map` が未生成のセンサ単体確認用に、Fixed Frame を `odom` へ切り替えやすい構成にする。
- Display は用途別にグループ化する。
- 起動直後に主要表示が有効であること。
- 重い表示は必要に応じて無効化できること。

推奨グループ:

| Group | Displays |
|---|---|
| Frames | TF, RobotModel |
| SLAM 2D | Map, LaserScan, Odometry |
| SLAM 2.5D | PointCloud2, OctoMap |
| Navigation | Global Costmap, Local Costmap, Global Plan, Local Plan |
| Safety | Hazard Status, Cmd Vel |

### V-02 RViz2 起動 launch

RViz2 を既定設定付きで起動する launch を作成する。

成果物:

```text
mobile_robot_server/launch/visualization_25d.launch.py
```

必須要件:

- `rviz2` executable を起動する。
- `rviz_config` launch argument で設定ファイルを差し替え可能にする。
- `use_sim_time` launch argument を持つ。
- rosbag replay 時は `use_sim_time:=true` で起動できること。
- GUI 環境がない場合にエラー理由が分かるよう README に注意を書くこと。

起動例:

```bash
ros2 launch mobile_robot_server visualization_25d.launch.py
ros2 launch mobile_robot_server visualization_25d.launch.py use_sim_time:=true
```

### V-03 2D Map 表示

`/map` を `Map` display で表示する。

必須要件:

- Topic は `/map`。
- Alpha は 0.7 から 1.0 の範囲で視認しやすくする。
- map 更新が途切れた場合、Topic status で確認できること。
- `slam_toolbox` 起動前でも RViz2 自体は起動できること。

受入基準:

- `slam_toolbox` 起動後、RViz2 上で OccupancyGrid が表示される。
- `map -> odom` TF が存在する状態で RobotModel と map が同一画面に表示される。

### V-04 OctoMap 表示

OctoMap を表示できる構成にする。

必須要件:

- `/octomap_binary` を第一候補 topic とする。
- 環境により `/octomap_full` も表示候補として用意する。
- RViz2 の OctoMap display plugin が必要な場合、依存 package を README に記載する。
- OctoMap 表示が利用できない環境でも、代替として `/lider/pointcloud2` を表示できること。

受入基準:

- `octomap_server` 起動後、RViz2 上で OctoMap または点群代替表示が確認できる。
- Fixed Frame `map` または `odom` で frame transform error が出ない。

### V-05 PointCloud2 表示

`/lider/pointcloud2` を表示する。

必須要件:

- Topic は `/lider/pointcloud2`。
- Style は `Points` または `Flat Squares`。
- Size は初期値 `0.02` m 程度。
- Color Transformer は `AxisColor` の `Z` または `Intensity` 相当を使用する。
- 点群が重い場合に Decay Time または Size を調整できること。

受入基準:

- `lider_module_node` 起動後、下向き点群が RViz2 で表示される。
- `/map`, RobotModel, `/lider/pointcloud2` の位置関係が TF 上で破綻しない。

### V-06 LaserScan 表示

`/scan` を表示する。

必須要件:

- Topic は `/scan`。
- Style は `Points`。
- Size は `0.03` m 程度。
- Color は 2D map と区別できる色にする。

受入基準:

- 実機または rosbag replay で、水平スキャンがロボット周囲に表示される。

### V-07 Nav2 costmap 表示

Nav2 の local/global costmap を表示する。

必須要件:

- `/global_costmap/costmap` を表示候補にする。
- `/local_costmap/costmap` を表示候補にする。
- local costmap は rolling window として robot 周辺に表示されること。
- voxel layer の効果確認のため、local costmap と `/lider/pointcloud2` を同時表示できること。

受入基準:

- `/scan` の障害物が local costmap に反映される。
- `/lider/pointcloud2` 由来の障害物が voxel layer 経由で local costmap に反映されることを目視確認できる。

### V-08 Safety / Hazard 表示

段差/穴検出状態と安全停止系の確認を行えるようにする。

必須要件:

- `/hazard/downward_status` を Topic display または別途簡易 monitor で確認できること。
- `/hazard/downward_stop` を確認できること。
- `/cmd_vel` を確認できること。
- collision monitor 起動時、出力 topic が確認できること。

受入基準:

- hazard node 未実装の場合でも RViz2 は起動できる。
- hazard node 実装後、状態 topic を同一プリセットで確認できる。

## 6. Launch / Package 要件

### 6.1 ファイル配置

Step1 の実装成果物は以下とする。

```text
mobile_robot_server/
  config/
    rviz/
      slam_25d.rviz
  launch/
    visualization_25d.launch.py
```

必要に応じて、`setup.py` または package install 設定に `config/rviz/*.rviz` と launch file が install されるよう追加する。

### 6.2 起動モード

| モード | コマンド例 | 用途 |
|---|---|---|
| 実機 SLAM 表示 | `ros2 launch mobile_robot_server visualization_25d.launch.py` | 通常確認 |
| rosbag replay 表示 | `ros2 launch mobile_robot_server visualization_25d.launch.py use_sim_time:=true` | 再現確認 |
| RViz 設定差替 | `ros2 launch mobile_robot_server visualization_25d.launch.py rviz_config:=/path/to/file.rviz` | 調整 |

### 6.3 依存 package

最低限:

- `rviz2`
- `robot_state_publisher`
- `tf2_ros`
- `slam_toolbox`
- `nav2_map_server`
- `nav2_costmap_2d`

OctoMap 表示用:

- `octomap_server`
- `octomap_msgs`
- RViz2 OctoMap display plugin を含む package

環境差があるため、OctoMap plugin 名は実装時に `ros2 pkg executables` と RViz2 plugin 一覧で確認する。

## 7. rosbag 対応要件

可視化検証用に、以下 topic を rosbag に記録できること。

```bash
/scan
/lider/pointcloud2
/lider/imu
/odom
/tf
/tf_static
/map
/octomap_binary
/octomap_full
/global_costmap/costmap
/local_costmap/costmap
/cmd_vel
/hazard/downward_status
/hazard/downward_stop
```

受入基準:

- 実機なしで rosbag replay し、RViz2 プリセットで `/map`, `/scan`, `/lider/pointcloud2`, TF が表示される。
- OctoMap topic が bag に含まれる場合、OctoMap も表示される。

## 8. Web ダッシュボード将来拡張要件

Web ダッシュボードは Step1 の必須成果物ではない。RViz2 でデバッグ用の表示項目が確定した後、運用者向けに軽量 UI として実装する。

### W-01 目的

Web ダッシュボードは、RViz2 を使わない利用者がブラウザからロボット状態、2D map、点群概要、OctoMap 概要、hazard 状態を確認できることを目的とする。

### W-02 想定構成

```mermaid
flowchart LR
    ROS["ROS 2 Topics"] --> BRIDGE["visualization_api_node\nrclpy + FastAPI/WebSocket"]
    BRIDGE --> WEB["Web Dashboard\nCanvas + Three.js"]
```

候補技術:

- backend: `rclpy` + `FastAPI` + WebSocket
- frontend: TypeScript, Canvas 2D, Three.js
- 2D map: OccupancyGrid を PNG または typed array に変換
- 3D: PointCloud2 を downsample して送信
- OctoMap: 初期は voxel/pointcloud 代替表示、必要時に OctoMap 変換を実装

### W-03 将来表示項目

| 表示 | 内容 |
|---|---|
| 2D Map | `/map` を平面表示 |
| Robot Pose | TF または `/odom` から姿勢表示 |
| LaserScan | `/scan` を 2D overlay |
| PointCloud | `/lider/pointcloud2` を downsample して 3D 表示 |
| OctoMap | 低解像度 voxel または点群代替表示 |
| Hazard | `SAFE`, `STEP_DOWN`, `HOLE`, `UNKNOWN` |
| Nav2 | goal, path, local/global costmap 概要 |
| Topic Health | topic 周期、最終受信時刻、欠落状態 |

### W-04 将来の非機能要件

- Raspberry Pi 上で backend が動作しても SLAM / Nav2 に大きな負荷を与えないこと。
- 点群は downsample、rate limit、範囲制限を必須とする。
- ブラウザ表示更新は 5 から 10 Hz を目標とする。
- 3D 点群は 1 から 2 Hz 程度に制限する。
- 操作系は初期実装では持たず、表示専用とする。
- 外部公開時は認証または LAN 内限定を必須とする。

## 9. 実装タスク定義

### VT-01 RViz2 設定作成

対象:

- `mobile_robot_server/config/rviz/slam_25d.rviz`

内容:

- Fixed Frame `map`
- TF, RobotModel, Map, LaserScan, PointCloud2, OctoMap, Costmap, Path, Odometry を登録
- 表示グループを整理
- 重い表示は無効化しやすくする

完了条件:

- RViz2 で設定を開き、主要 display が保存されている。

### VT-02 visualization launch 作成

対象:

- `mobile_robot_server/launch/visualization_25d.launch.py`

内容:

- `rviz2 -d slam_25d.rviz` を起動
- `rviz_config` と `use_sim_time` の launch argument を追加

完了条件:

- `ros2 launch mobile_robot_server visualization_25d.launch.py` で RViz2 が起動する。

### VT-03 package install 設定

対象:

- `mobile_robot_server/setup.py`

内容:

- `config/rviz/*.rviz` が install されるようにする。
- launch file が install されることを確認する。

完了条件:

- `colcon build --packages-select mobile_robot_server` 後、install share 配下に RViz 設定が配置される。

### VT-04 rosbag 可視化手順

対象:

- `docs` または `mobile_robot_server/README.md`

内容:

- rosbag record 対象 topic を記載
- rosbag replay + RViz2 起動手順を記載
- `use_sim_time:=true` の使い方を記載

完了条件:

- 実機なしで bag replay から可視化できる。

### VT-05 Web ダッシュボード設計メモ

対象:

- 将来用 docs

内容:

- RViz2 で確定した表示項目を Web UI 要件へ転記する。
- backend / frontend の責務を分ける。
- 表示専用、rate limit、downsample 方針を明記する。

完了条件:

- Web 実装着手前の仕様として参照できる。

## 10. 受入試験

| 試験 | 条件 | 合格基準 |
|---|---|---|
| RViz 起動 | GUI 環境あり | `visualization_25d.launch.py` で RViz2 が起動 |
| 2D Map 表示 | `/map` 配信あり | map が表示される |
| TF 表示 | `/tf`, `/tf_static` 配信あり | frame transform error がない |
| LaserScan 表示 | `/scan` 配信あり | ロボット周囲に scan が表示される |
| PointCloud 表示 | `/lider/pointcloud2` 配信あり | 下向き点群が表示される |
| OctoMap 表示 | `/octomap_binary` 配信あり | OctoMap または代替点群が表示される |
| Costmap 表示 | Nav2 起動済み | local/global costmap が表示される |
| rosbag 表示 | bag replay | 実機なしで map/scan/pointcloud/TF が表示される |
| 欠落耐性 | 一部 topic 未配信 | RViz2 自体は起動し、未配信 display の status で確認できる |

## 11. 完了の定義

Step1 は以下を満たした時点で完了とする。

- `mobile_robot_server/config/rviz/slam_25d.rviz` が存在する。
- `mobile_robot_server/launch/visualization_25d.launch.py` が存在する。
- RViz2 で `/map`, `/scan`, `/lider/pointcloud2`, TF, RobotModel を確認できる。
- OctoMap topic がある場合に表示、ない場合も PointCloud2 で 3D 情報を確認できる。
- Nav2 local/global costmap を表示できる。
- rosbag replay 時に `use_sim_time:=true` で確認できる。
- Web ダッシュボードは将来拡張として、本書の W-01 から W-04 に従う。

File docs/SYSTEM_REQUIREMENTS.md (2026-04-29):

# モバイルロボット システム要件定義書

> 更新: 2026-04 — LiderModule (YDLIDAR T-mini Pro + STS3215 チルト) 統合後の構成を反映

---

## 1. システム概要

差動二輪モバイルロボットの自律走行システム。Raspberry Pi (エッジ) と Ubuntu デスクトップ (サーバー) の2ノード構成で、LiDAR SLAM・Nav2・LLM ナビゲーションを実現する。

### 1.1 構成図

```
┌─────────────────────────────────────────────────────────────────┐
│  Ubuntu Server (デスクトップ PC)                                  │
│                                                                   │
│  slam_toolbox ─── /map ──────────────────────────────────────── │
│  (LiDAR SLAM)     /tf(map→odom)                                  │
│       ↑                                                           │
│     /scan ◄── [Zenoh / WiFi] ◄─────────────────────────────┐    │
│                                                             │    │
│  Nav2 ─── /cmd_vel ─── [Zenoh / WiFi] ───────────────────┐ │    │
│                                                           │ │    │
│  llm_nav_controller (YOLO yolov8s + Ollama qwen3.5:9b)   │ │    │
│       ↑ /camera/image_raw                                │ │    │
└───────────────────────────────────────────────────────────┼─┼────┘
            Zenoh / WiFi                                    │ │
┌───────────────────────────────────────────────────────────┼─┼────┐
│  Raspberry Pi (エッジ)                                    │ │    │
│                                                           │ │    │
│  lider_module_node ──── /scan ────────────────────────────┘ │    │
│  (USB CDC /dev/ttyACM0) /lider/pointcloud2                  │    │
│                         /lider/imu                          │    │
│                                ↑                            │    │
│  LiderModule                   │                            │    │
│  (XIAO ESP32-C3 +              │                            │    │
│   YDLIDAR T-mini Pro +         │                            │    │
│   STS3215 チルトサーボ)         │                            │    │
│                                                             │    │
│  ws_odometry_publisher ──── /odom ──────────────────────────┘    │
│  ws_motor_controller ◄──── /cmd_vel ──────────────────────────── │
│  ws_camera_bridge ──── /camera/image_raw/compressed ─────────── │
│                                                                   │
│  edge_services (ホスト側 Python)                                  │
│  ├ motor_service (ws :8001) ── PR2040 ── 4× DC モーター           │
│  ├ odometry_service (ws :8002) ── エンコーダー読み取り             │
│  └ camera_service (ws :8003) ── Raspberry Pi カメラ              │
└─────────────────────────────────────────────────────────────────┘
```

---

## 2. ハードウェア要件

### 2.1 エッジ (Raspberry Pi)

| コンポーネント | 仕様 | 接続 |
|---|---|---|
| **Raspberry Pi 4 / 5** | 4GB RAM 以上推奨 | — |
| **Raspberry Pi Camera Module 3** | HQ カメラ / 固定フォーカス | CSI |
| **PR2040 モータードライバー** | I2C addr 0x60、4ch PWM | I2C-1 (`/dev/i2c-1`) |
| **DC モーター × 4** | エンコーダー付き、720 CPR | PR2040 ドライバー経由 |
| **LiderModule** | XIAO ESP32-C3 + T-mini Pro + STS3215 | USB (`/dev/ttyACM0`) |

#### LiderModule 詳細

| コンポーネント | 型番 | 仕様 |
|---|---|---|
| マイコン | Seeed XIAO ESP32-C3 | RISC-V 160 MHz, 400 KB RAM, USB CDC |
| LiDAR | YDLIDAR T-mini Pro | 360°, 4000 pts/s, 0.02–12 m, 6 Hz 回転 |
| チルトサーボ | FEETECH STS3215 | 7.4 V, 12 bit エンコーダー, 1 Mbps TTL |
| IMU | MPU6050 | 6 DoF, DMP, I2C addr 0x68 |
| チルト範囲 | −45° 〜 +45° | サーボ ID = 1, センター位置 = 2048 |

### 2.2 サーバー (Ubuntu デスクトップ)

| コンポーネント | 仕様 |
|---|---|
| **CPU** | x86_64、マルチコア (ROS2 + YOLO 同時実行) |
| **GPU** | NVIDIA RTX 4060 (YOLO 推論、CUDA 必須) |
| **RAM** | 16 GB 以上推奨 |
| **OS** | Ubuntu 24.04 (Noble) |

---

## 3. ソフトウェア要件

### 3.1 エッジ (Raspberry Pi)

#### OS・ランタイム

| ソフトウェア | バージョン | 役割 |
|---|---|---|
| Raspberry Pi OS (64 bit) | Bookworm | ベース OS |
| Python | 3.11+ | edge_services、スクリプト |
| Docker | 最新 | ROS2 コンテナ実行 |
| Docker Compose | v2 | コンテナ管理 |

#### Docker コンテナ (ROS2)

| ソフトウェア | バージョン | 役割 |
|---|---|---|
| ROS 2 Jazzy | ros:jazzy-ros-base | ROS2 ベース |
| ros-jazzy-nav2-bringup | — | Nav2 スタック |
| ros-jazzy-image-transport | — | カメラトランスポート |
| ros-jazzy-cv-bridge | — | 画像変換 |
| pyserial | ≥ 3.5 | LiderModule USB CDC 通信 |
| numpy | ≥ 1.21 | 座標変換 |
| smbus2 | ≥ 0.4 | I2C 通信 |
| websockets | ≥ 10.0 | edge_services WebSocket |
| openai | 最新 | LLM クライアント |

#### edge_services (ホスト側 Python)

| ソフトウェア | バージョン |
|---|---|
| smbus2 | ≥ 0.4.0 |
| websockets | ≥ 10.0 |
| opencv-python | ≥ 4.5.0 |
| numpy | ≥ 1.20.0 |

#### LiderModule ファームウェア

| ソフトウェア | バージョン |
|---|---|
| Arduino IDE | 2.x |
| Seeed XIAO ESP32-C3 ボードパッケージ | 最新 |
| SCServo ライブラリ | 最新 |
| MPU6050 (i2cdevlib DMP版) | 最新 |
| **ビルド設定** | USB CDC On Boot: **Enabled** |

### 3.2 サーバー (Ubuntu デスクトップ)

| ソフトウェア | バージョン | 役割 |
|---|---|---|
| ROS 2 Jazzy | ros:jazzy | ROS2 スタック |
| slam_toolbox | ros-jazzy-slam-toolbox | 2D LiDAR SLAM |
| Nav2 | ros-jazzy-nav2-bringup 他 | 自律走行スタック |
| Ollama | 最新 | ローカル LLM サーバー |
| qwen3.5:9b-nav | Ollama モデル | ナビゲーション推論 |
| YOLO (ultralytics) | yolov8s.pt | 物体検出 |
| rmw_zenoh_cpp | ros-jazzy | エッジ↔サーバー通信 |
| image_transport | ros-jazzy | 画像圧縮転送 |

---

## 4. ROS2 トピック・インターフェース

### 4.1 エッジ発行 (RPi → Server via Zenoh)

| トピック | 型 | 発行元 | 周期 | 説明 |
|---|---|---|---|---|
| `/scan` | `sensor_msgs/LaserScan` | `lider_module_node` | ~5 Hz | tilt=0° 水平 360° スキャン |
| `/lider/pointcloud2` | `sensor_msgs/PointCloud2` | `lider_module_node` | 30 秒ごと | DOWN_ANGLES 24 ステップ 3D 点群 |
| `/lider/imu` | `sensor_msgs/Imu` | `lider_module_node` | 50 Hz | MPU6050 DMP 姿勢 (pitch/roll/yaw) |
| `/odom` | `nav_msgs/Odometry` | `ws_odometry_publisher` | 50 Hz | ホイールエンコーダー里程計 |
| `/camera/image_raw/compressed` | `sensor_msgs/CompressedImage` | `ws_camera_bridge` | 30 Hz | カメラ映像 (JPEG 圧縮) |
| `/camera/camera_info` | `sensor_msgs/CameraInfo` | `ws_camera_bridge` | 30 Hz | カメラ内部パラメーター |
| `/tf` | `tf2_msgs/TFMessage` | `robot_state_publisher` | 30 Hz | odom → base_footprint → base_link |

### 4.2 サーバー発行 (Server → RPi via Zenoh)

| トピック | 型 | 発行元 | 説明 |
|---|---|---|---|
| `/cmd_vel` | `geometry_msgs/Twist` | Nav2 / `llm_nav_controller` | 速度コマンド |
| `/goal_pose` | `geometry_msgs/PoseStamped` | `llm_nav_controller` | Nav2 ゴール |
| `/map` | `nav_msgs/OccupancyGrid` | `slam_toolbox` | 5 cm 解像度 OGM |
| `/tf` | `tf2_msgs/TFMessage` | `slam_toolbox` | map → odom |

### 4.3 TF フレームツリー

```
map
└── odom
    └── base_footprint
        └── base_link
            ├── camera_link
            │   └── camera_optical_frame
            ├── laser_frame          ← LiderModule チルト軸中心
            │   └── imu_link         ← MPU6050
            └── [wheel links]
```

---

## 5. デバイスマッピング

### 5.1 Raspberry Pi デバイス

| デバイス | 用途 | 備考 |
|---|---|---|
| `/dev/ttyACM0` | LiderModule (XIAO ESP32-C3 USB CDC) | 921600 baud, DTR=False |
| `/dev/i2c-1` | PR2040 モータードライバー | addr 0x60 |
| `/dev/video0` | Raspberry Pi Camera Module 3 | v4l2 |
| `/dev/ttyUSB0` | 予備 (旧 YDLIDAR 等) | 現在未使用 |

### 5.2 Docker デバイスマウント

```yaml
devices:
  - /dev/i2c-1:/dev/i2c-1
  - /dev/video0:/dev/video0
  - /dev/ttyUSB0:/dev/ttyUSB0
  - /dev/ttyUSB1:/dev/ttyUSB1
  - /dev/ttyACM0:/dev/ttyACM0     # LiderModule
```

---

## 6. ロボット物理パラメーター

| パラメーター | 値 | 単位 |
|---|---|---|
| ホイールベース | 0.16 | m |
| ホイール半径 | 0.033 | m |
| エンコーダー分解能 | 720 | CPR |
| 最大直進速度 | 0.5 | m/s |
| 最大旋回速度 | 2.0 | rad/s |
| base_link 高さ | 0.033 | m (base_footprint から) |
| laser_frame 位置 | x=0.05, z=0.08 | m (base_link から) |

---

## 7. SLAM パラメーター (slam_toolbox)

| パラメーター | 値 | 説明 |
|---|---|---|
| `scan_topic` | `/scan` | LiderModule からの LaserScan |
| `resolution` | 0.05 m | マップ解像度 (5 cm) |
| `max_laser_range` | 12.0 m | T-mini Pro 最大レンジ |
| `mode` | mapping | オンライン非同期マッピング |
| `minimum_travel_distance` | 0.10 m | キーフレーム追加しきい値 |
| `minimum_travel_heading` | 0.087 rad | キーフレーム追加しきい値 (~5°) |
| `map_update_interval` | 3.0 s | Nav2 向けマップ配信間隔 |
| `solver_plugin` | CeresSolver | 最適化ソルバー |

---

## 8. LiderModule スキャンパラメーター

| パラメーター | 値 | 説明 |
|---|---|---|
| `port` | `/dev/ttyACM0` | USB CDC シリアルポート |
| `scan_frame_id` | `laser_frame` | LaserScan/PointCloud2 フレーム |
| `imu_frame_id` | `imu_link` | IMU フレーム |
| `min_range_m` | 0.02 | 最小有効距離 |
| `max_range_m` | 12.0 | 最大有効距離 |
| `laser_scan_bins` | 720 | LaserScan 角度分解能 (0.5°/bin) |
| `slice_timeout_s` | 4.0 | スライス受信タイムアウト |
| `pointcloud_interval_s` | 30.0 | 3D スキャン周期 (0 で無効) |

### DOWN_ANGLES パターン (24 ステップ)

```python
DOWN_ANGLES = [
    0.0,   -15.0, -30.0, -45.0,
    -42.5, -27.5, -12.5,   0.0,
    -5.0,  -20.0, -35.0, -45.0,
    -37.5, -22.5,  -7.5,   0.0,
    -10.0, -25.0, -40.0, -45.0,
    -32.5, -17.5,  -2.5,   0.0,
]
```

実測: 24 スライス → 約 1925 点、所要時間 約 8.5 秒

---

## 9. WebSocket サービス (edge_services)

| サービス | ポート | 役割 |
|---|---|---|
| `motor_service.py` | ws://localhost:8001 | `/cmd_vel` → PR2040 → モーター |
| `odometry_service.py` | ws://localhost:8002 | エンコーダー → `/odom` |
| `camera_service.py` | ws://localhost:8003 | カメラ映像 → `/camera/image_raw/compressed` |

---

## 10. 起動手順

### 10.1 Raspberry Pi (エッジ)

```bash
# 1. edge_services 起動
cd /home/pi/MobileRobot/edge_services
python3 launch_all.py &

# 2. ROS2 コンテナ起動
cd /home/pi/MobileRobot/ros2_docker
sudo docker compose run --rm ros2 bash -c \
  "source /ros2_ws/install/setup.bash && \
   ros2 launch mobile_robot_edge ws_edge_bringup.launch.py"
```

### 10.2 Ubuntu サーバー

```bash
# Ollama 起動 (別ターミナル)
ollama serve &
ollama pull qwen3.5:9b-nav

# ROS2 サーバー起動
cd ~/ros2_ws
colcon build --packages-select mobile_robot_server
source install/setup.bash
ros2 launch mobile_robot_server server_bringup.launch.py

# 自律マッピング有効化 (オプション)
ros2 launch mobile_robot_server server_bringup.launch.py autonomous_mapping:=true
```

### 10.3 ビルド (変更後)

```bash
# Docker コンテナ内でビルド
cd /home/pi/MobileRobot/ros2_docker
docker compose run --rm ros2 bash -c \
  "source /opt/ros/jazzy/setup.bash && \
   cd /ros2_ws && \
   colcon build --packages-select mobile_robot_edge mobile_robot_server"
```

---

## 11. ファイル構成

```
MobileRobot/
├── ros2_docker/
│   ├── Dockerfile                  # ROS2 Jazzy コンテナ定義
│   ├── docker-compose.yml          # デバイスマウント・ボリューム設定
│   └── ros2_workspace/             # colcon ビルド出力 (install/)
│
├── mobile_robot_edge/              # ROS2 エッジパッケージ
│   ├── mobile_robot_edge/
│   │   ├── lider_module_node.py    # LiderModule USB CDC → /scan, /lider/*
│   │   ├── ws_motor_controller.py  # /cmd_vel → WebSocket → motor_service
│   │   ├── ws_odometry_publisher.py# WebSocket → /odom
│   │   └── ws_camera_bridge.py     # WebSocket → /camera/*
│   └── launch/
│       └── ws_edge_bringup.launch.py
│
├── mobile_robot_server/            # ROS2 サーバーパッケージ
│   ├── mobile_robot_server/
│   │   ├── llm_nav_controller.py   # YOLO + Ollama LLM ナビゲーション
│   │   └── autonomous_mapping.py   # フロンティア探索 + LLM 判断
│   ├── config/
│   │   ├── slam_toolbox_params.yaml
│   │   ├── nav2_params.yaml
│   │   └── rtabmap_params.yaml
│   └── launch/
│       └── server_bringup.launch.py
│
├── edge_services/                  # ホスト側 WebSocket サービス
│   ├── motor_service.py            # ws :8001
│   ├── odometry_service.py         # ws :8002
│   ├── camera_service.py           # ws :8003
│   └── launch_all.py
│
└── LiderModule/                    # LiderModule ハードウェア一式
    ├── SPEC.md                     # ハードウェア・ファームウェア仕様書
    ├── firmware/lidar_tilt_3d/
    │   └── lidar_tilt_3d.ino       # XIAO ESP32-C3 ファームウェア
    ├── host/rpi_tilt_3d.py         # スタンドアロン 3D スキャンツール
    ├── docs/USB_CDC_COMMAND_MANUAL.md
    └── 計測パターン.csv
```

---

## 12. 既知の制約・注意事項

| 項目 | 内容 |
|---|---|
| `/scan` レート | ~5 Hz (LiDAR 6 Hz × 1 スキャン/コマンド)。slam_toolbox は `minimum_time_interval: 0.5s` で許容範囲内 |
| LiDAR モーター起動遅延 | CMD_SCAN_STOP 直後の CMD_SCAN_START は初回スキャン取得が遅れる場合あり |
| IMU yaw | MPU6050 DMP 6 軸のため絶対方位不可。相対角として扱う |
| サーボ安定待ち | `SCAN_SETTLE_DISABLED=1` (待ちなし)。障害物検出に有効だが点群精度は低下 |
| PointCloud2 の座標 | `/scan` (tilt=0°) との整合性は IMU 補正前提。動的シーンでは使用注意 |
| Docker デバイス | `docker-compose.yml` に `/dev/ttyACM0` 要記載。LiderModule 未接続時はノードがエラー終了 |
| USB テキストデバッグ | ファームウェアの `USB_TEXT_DEBUG_MODE=1` 時はバイナリプロトコル無効。運用時は `0` に設定 |

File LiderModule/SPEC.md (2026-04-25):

# 3D LiDAR Scanner System — 要件定義・実装仕様書

> 更新メモ (実機反映): 2026-04 時点の検証結果に基づき、IMUはDMPベース、LiDARモーターは必要時のみ起動、サーボUARTは起動時自動再試行の仕様を反映。

## 1. プロジェクト概要

### 1.1 目的

2D LiDAR（YDLIDAR T-mini Pro）をサーボモーター（FEETECH STS3215）で上下に傾斜（チルト）させることで、低コストに3Dポイントクラウドを取得するシステムを構築する。

### 1.1.1 責務分離ポリシー

- **LiderModule (ESP32-S3)**: センシング品質に専念する。具体的には LiDAR点群、チルト角、IMU姿勢、取得タイミング整合を安定して生成・送信する。
- **Raspberry Pi (Host)**: 意味解釈・判断を担当する。具体的には段差/穴の検出、危険度判定、走行可否判断、制御系への通知を実装する。

注記:
- 本仕様のUSB CDCプロトコルは「生に近い観測情報の送信」を優先し、段差/穴の最終判定ロジックはプロトコル外（Host側アルゴリズム）とする。

### 1.2 システム構成

```
┌─────────────────────────────────────────────────────────┐
│  Raspberry Pi (Host)                                     │
│  - 3Dポイントクラウド再構成                                │
│  - リアルタイム可視化 (Open3D / matplotlib)                │
│  - PLY/CSV ファイル保存                                   │
│  - スキャン制御コマンド送信                                │
└────────────────────┬────────────────────────────────────┘
                     │ USB CDC (/dev/ttyACM0)
                     │ Binary protocol
┌────────────────────┴────────────────────────────────────┐
│  Seeed バスサーボドライバーボード for XIAO                  │
│  ┌──────────────────────────────┐                        │
│  │  XIAO ESP32-S3 (差し込み装着)  │                        │
│  │  - LiDARデータ受信・解析       │                        │
│  │  - IMUデータ取得・フィルタ      │                        │
│  │  - サーボ制御                  │                        │
│  │  - 3Dスキャン状態機械          │                        │
│  │  - USB CDCバイナリ通信         │                        │
│  └──────────────────────────────┘                        │
│  DC IN (7.4V) → サーボ電源                                │
│  サーボコネクタ → STS3215                                  │
└─────────────────────────────────────────────────────────┘
        │ UART1         │ I2C
        ▼               ▼
  YDLIDAR T-mini Pro  MPU6050 IMU
  (5V別電源)          (3.3V XIAO給電)
```

### 1.3 動作概要

1. RPi から3Dスキャン開始コマンドを送信
2. ESP32-S3 がサーボを -45° → +45° まで連続スイープ（停止なし）
3. スイープ中に LiDAR の360°スキャン1回転分ごとにスライス化して取得
4. チルト角度 + IMU姿勢 + LiDARスキャンデータを1スライスとしてRPiに送信
5. RPi側で座標変換し、3Dポイントクラウドを構築
6. スキャン完了後、PLY/CSV保存 or リアルタイム表示

---

## 2. ハードウェア仕様

### 2.1 コンポーネント一覧

| コンポーネント | 型番 | 数量 | 主な仕様 |
|---|---|---|---|
| マイコン | Seeed XIAO ESP32-S3 | 1 | Xtensa LX7 dual-core 240MHz, 512KB SRAM + 8MB PSRAM, USB CDC, WiFi/BLE |
| サーボドライバー | Seeed バスサーボドライバーボード for XIAO | 1 | GH1.25コネクタ、UART半二重変換、DC IN 5.5×2.1mm |
| サーボモーター | FEETECH STS3215 (7.4V版) | 1 | 7.4V, 19.5kg·cm stall, 12bit磁気エンコーダ, 4096ステップ/360°, TTLシリアルバス 1Mbps |
| LiDAR | YDLIDAR T-mini Pro | 1 | 360° ToF, 4000pts/s, 0.02-12m, UART 230400bps, 3.3Vレベル, GH1.25-4P |
| IMU | MPU6050 (ブレイクアウトボード) | 1 | 6DoF, I2C 400kHz, addr 0x68, 3.3V動作 |
| ホスト | Raspberry Pi 4/5 | 1 | USB接続、Python 3.9+ |

### 2.2 電源設計

| 電源 | 電圧 | 電流容量 | 供給先 | 接続 |
|---|---|---|---|---|
| 7.4V (2S LiPo or ACアダプタ) | 7.4V | 3A以上 | STS3215 サーボ | ドライバーボード DC IN (5.5×2.1mm) |
| 5V (DC-DCコンバータ or USB) | 5V | 1.5A以上 | LiDAR T-mini Pro, XIAO ESP32-S3 | LiDAR VCC, XIAO USB-C |
| 3.3V (XIAO内蔵レギュレータ) | 3.3V | — | MPU6050 | XIAO 3.3Vピン |

> **注意**: 7.4V→5V DC-DC (例: MP1584) を使えば1電源に統一可能。GNDは全デバイスで共通化必須。

### 2.3 ピンアサイン（XIAO ESP32-S3）

| XIAOピン | GPIO | 機能 | 接続先 | プロトコル | 備考 |
|---|---|---|---|---|---|
| D6 | GPIO43 | UART0 TX | サーボドライバーボード内部配線 | TTL 1Mbps | ボードに差し込むだけ |
| D7 | GPIO44 | UART0 RX | サーボドライバーボード内部配線 | TTL 1Mbps | ボードに差し込むだけ |
| D2 | GPIO3 | UART1 RX | T-mini Pro Pin2 (TX) | 230400bps | 外部配線必要 |
| D3 | GPIO4 | UART1 TX | T-mini Pro Pin4 (RX) | 230400bps | 外部配線必要 |
| D4 | GPIO5 | I2C SDA | MPU6050 SDA | 400kHz | 外部配線必要 |
| D5 | GPIO6 | I2C SCL | MPU6050 SCL | 400kHz | 外部配線必要 |
| USB-C | GPIO19/20 (内蔵USB D-/D+) | USB CDC | Raspberry Pi | Binary protocol | XIAOのUSBポート |
| D0, D1, D8, D9, D10 | GPIO1, GPIO2, GPIO7, GPIO8, GPIO9 | 未使用 | — | — | 拡張用予備 |

### 2.4 LiDAR接続 (GH1.25-4P)

| T-mini Pro Pin | 信号 | 接続先 |
|---|---|---|
| Pin1: VCC | 5V | 外部5V電源 (+) |
| Pin2: TX | UART出力 (3.3V) | XIAO D2 (GPIO3, RX1) |
| Pin3: GND | 0V | 共通GND |
| Pin4: RX | UART入力 (3.3V) | XIAO D3 (GPIO4, TX1) |

> レベル変換不要。T-mini ProのUART信号は3.3Vレベル。

### 2.5 MPU6050接続

| MPU6050 Pin | 接続先 |
|---|---|
| VCC | XIAO 3.3V |
| GND | 共通GND |
| SDA | XIAO D4 (GPIO5) |
| SCL | XIAO D5 (GPIO6) |
| AD0 | GND (I2Cアドレス = 0x68) |

### 2.6 サーボドライバーボード設定

- **UART接続モード**を使用（USB接続モードではない）
- ボード前面の2ピンジャンパーキャップは**短絡しない**（デフォルト状態のまま）
- ボード裏面のはんだジャンパーは変更不要
- XIAOをボードのヘッダーに直接差し込んで使用
- STS3215はサーボコネクタにデイジーチェーン接続

### 2.7 機械構成

- STS3215の出力軸にLiDAR T-mini Proをマウント
- **チルト軸**: 水平 = 0°, 上向き = +, 下向き = -
- **チルト範囲**: -45° 〜 +45° (合計90°)
- STS3215のID = 1
- STS3215のセンター位置 = 2048 (12bit中点、水平0°に対応)

---

## 3. 通信プロトコル仕様

### 3.1 フレーム形式

ESP32-S3 ↔ Raspberry Pi 間のUSB CDCバイナリプロトコル。

```
[SYNC1][SYNC2][TYPE][LEN_L][LEN_H][PAYLOAD...][CHECKSUM]
  0xFE   0xEF  1byte  ---- 2byte ----  LEN bytes   XOR
```

| フィールド | サイズ | 説明 |
|---|---|---|
| SYNC1 | 1 byte | 0xFE (固定) |
| SYNC2 | 1 byte | 0xEF (固定) |
| TYPE | 1 byte | パケットタイプ |
| LEN_L | 1 byte | ペイロード長の下位バイト |
| LEN_H | 1 byte | ペイロード長の上位バイト |
| PAYLOAD | LEN bytes | データ本体 |
| CHECKSUM | 1 byte | TYPE ^ LEN_L ^ LEN_H ^ (全PAYLOADバイトのXOR) |

### 3.2 パケットタイプ

#### ESP32 → RPi (データ送信)

| Type | 名称 | 送信頻度 | Payload構造 |
|---|---|---|---|
| 0x02 | IMU data | 50Hz | `[pitch_f32][roll_f32][yaw_f32]` (12 bytes) |
| 0x04 | 3D scan slice | 各チルトステップ完了時 | 下記参照 |
| 0x05 | 3D scan status | 状態変化時 | `[state_u8][step_u16][total_u16]` (5 bytes) |

#### RPi → ESP32 (コマンド送信)

| Type | 名称 | Payload構造 |
|---|---|---|
| 0x10 | Servo angle (マニュアル) | `[angle_deg_f32]` (4 bytes) |
| 0x12 | 3D scan start | `[tilt_min_f32][tilt_max_f32][tilt_step_f32]` (12 bytes) またはペイロード0でデフォルト値使用 |
| 0x13 | 3D scan stop | ペイロードなし (LEN=0) |

### 3.3 3D scan slice (0x04) 詳細

```
Offset  Size  Field
0       4     tilt_deg      (float32) サーボ目標チルト角度 [度]
4       4     tilt_start    (float32) スライス取得開始時の実チルト [度]
8       4     tilt_end      (float32) スライス取得終了時の実チルト [度]
12      4     imu_pitch     (float32) IMU pitch [度]
16      4     imu_roll      (float32) IMU roll [度]
20      2     count         (uint16)  ポイント数 N
22      5×N   points        各ポイント:
                              [0-1] angle_x100 (uint16) LiDAR角度×100
                              [2-3] dist_mm    (uint16) 距離 [mm]
                              [4]   quality    (uint8)  信号品質
```

備考:

- 取得中サーボを動かしたまま計測し、`tilt_start -> tilt_end` を点数分補間して螺旋状に再構成する。
- 旧フォーマット (`tilt, imu_pitch, imu_roll, count`, 14 bytes header) を受信した場合は
  `tilt_start = tilt_end = tilt` として扱う。

### 3.4 3D scan status (0x05) 詳細

| state値 | 意味 |
|---|---|
| 0 | スキャン開始 |
| 1 | 進行中 (step/total で進捗表示) |
| 2 | スキャン完了 |

### 3.5 USB CDC設定

- ボーレート: 921600 (USB CDCは実質ボーレート無関係だが設定必要)
- Arduino IDE設定: **USB CDC On Boot = Enabled**
- RPi側デバイス: `/dev/ttyACM0`
- DTR/RTS: 無効化 (ESP32リセット防止)

---

## 4. ESP32-S3 ファームウェア仕様

### 4.1 開発環境

- **IDE**: Arduino IDE 2.x
- **ボード**: Seeed Studio XIAO ESP32-S3
- **必須ライブラリ**:
  - `SCServo` — Feetech STS/SCS サーボ制御 (https://github.com/workloads/scservo)
  - `MPU6050` — i2cdevlibベース DMPサポート版 (MotionApps20)
  - `Wire` — I2C (Arduino標準)
- **ボード設定**:
  - USB CDC On Boot: **Enabled**
  - Upload Speed: 921600

### 4.2 シリアルポート割り当て

```c
// USB CDC → Raspberry Pi (バイナリプロトコル)
Serial    // USBSerial (CDC)

// UART0 → STS3215 サーボ (ドライバーボード内部配線)
Serial0   // HardwareSerial(0), pins D6(GPIO43)/D7(GPIO44), 1Mbps

// UART1 → YDLIDAR T-mini Pro (外部配線)
HardwareSerial LidarSerial(1);  // pins D2(RX)/D3(TX), 230400bps
```

### 4.3 定数定義

```c
// ピン
#define LIDAR_RXD     3    // D2 = GPIO3
#define LIDAR_TXD     4    // D3 = GPIO4
#define IMU_SDA       5    // D4 = GPIO5
#define IMU_SCL       6    // D5 = GPIO6

// デバイス
#define MPU6050_ADDR      0x68
#define SERVO_ID_TILT     1
#define SERVO_CENTER      2048   // 水平0° = 12bit中点

// 通信速度
#define LIDAR_BAUDRATE    230400
#define SERVO_BAUDRATE    1000000
#define USB_BAUDRATE      921600

// プロトコル
#define PROTO_SYNC1       0xFE
#define PROTO_SYNC2       0xEF

// 3Dスキャンデフォルト値
#define TILT_MIN_DEFAULT    -45.0f  // 度
#define TILT_MAX_DEFAULT     45.0f
#define TILT_STEP_DEFAULT     2.0f
#define TILT_SAFE_LIMIT      50.0f  // サーボ保護上限

// タイミング
#define SCAN_SETTLE_DISABLED   1    // 1: 安定待ちなしで即時計測
#define SETTLE_MS_MIN        150    // 安定待ち有効時の最小待ち [ms]
#define SETTLE_MS_MAX       1300    // 安定待ち有効時の最大待ち [ms]
#define IMU_READ_MS           10    // IMU読み取り周期 (100Hz)
#define IMU_SEND_MS           50    // IMU送信周期 (50Hz)
```

### 4.4 LiDARパケットパーサー

T-mini Proのデータフォーマット:

```
[0xAA][0x55][CT][LSN][FSA_L][FSA_H][LSA_L][LSA_H][CS_L][CS_H][Si...]
```

- ヘッダ: 0xAA 0x55
- CT: パケットタイプ (bit0=1 で新スキャン開始)
- LSN: サンプル数
- FSA: 開始角度 (上位15bit / 64 = 度)
- LSA: 終了角度
- Si: 各ポイント3バイト (quality, dist_L, dist_H)

**パーサー状態機械**:
```
WAIT_H1 → WAIT_H2 → READ_CT → READ_LSN → READ_DATA → (処理) → WAIT_H1
```

**1スキャン完了検出**: CT の bit0 が 1 になった時、前回蓄積分を1スキャンとして確定。

### 4.5 MPU6050 初期化・読み取り (DMP適用)

- 使用ライブラリ: `MPU6050_6Axis_MotionApps20`
- I2C: 400kHz, アドレス `0x68`
- 初期化フロー:
  1. `mpu.initialize()`
  2. `mpu.dmpInitialize()`
  3. `mpu.setDMPEnabled(true)`
  4. `dmpGetFIFOPacketSize()` を保持
- 更新フロー:
  - `dmpGetCurrentFIFOPacket()` で最新FIFOを取得
  - `dmpGetQuaternion()`, `dmpGetGravity()`, `dmpGetYawPitchRoll()` で姿勢角を算出
  - 送信は従来どおり `MSG_IMU_DATA = [pitch, roll, yaw] (float32 x3)`

```
imuYaw   = ypr[0] * 180 / PI
imuPitch = ypr[1] * 180 / PI
imuRoll  = ypr[2] * 180 / PI
```

注記:
- 6軸DMPのため yaw は相対方位として扱う（磁気北の絶対方位ではない）。

### 4.6 3Dスキャン状態機械

```
S3D_IDLE ──(CMD_3DSCAN_START)──→ S3D_MOVING
                                    │
                                    ▼
                              setTiltAngle(current)
                                    │
                                    ▼
                              S3D_SETTLING ──(待ち0ms)──→ S3D_CAPTURING
                                                                    │
                                                                    ▼
                                                              (scanComplete==true)
                                                                    │
                                                                    ▼
                                                              S3D_SENDING
                                                                    │
                                                          send3DSlice() + send3DStatus()
                                                                    │
                                                              stepIndex++
                                                                    │
                                                        ┌───(範囲内)───┐
                                                        ▼             ▼
                                                   S3D_MOVING    S3D_COMPLETE
                                                                    │
                                                              setTiltAngle(0°)
                                                              send3DStatus(2,...)
                                                                    │
                                                                    ▼
                                                               S3D_IDLE
```

### 4.7 サーボ角度変換

```c
// 角度(度) → STS3215ポジション (0-4095)
int16_t pos = SERVO_CENTER + (int16_t)(angleDeg * 4096.0f / 360.0f);
pos = constrain(pos, 0, 4095);

// 分解能: 360° / 4096 ≈ 0.088°/step
```

### 4.8 loop() の処理優先度

```
1. LiDAR UART受信 (while available, ノンブロッキング) ← 最優先
2. RPi USBコマンド受信 (while available)
3. IMU読み取り (10ms周期)
4. IMUデータ送信 (50ms周期)
5. 3Dスキャン状態機械更新
```

> ESP32-S3 はデュアルコアだが、Arduinoの `loop()` は実質単一タスクとして扱うため、受信処理はノンブロッキング前提で設計する。
> LiDAR受信処理はループ占有防止のため1回あたり処理バジェット（上限バイト数）を設ける。

---

## 5. Raspberry Pi ソフトウェア仕様

### 5.1 開発環境

- **言語**: Python 3.9+
- **必須パッケージ**: `pyserial`, `numpy`
- **推奨パッケージ**: `open3d` (3D可視化), `matplotlib` (フォールバック)

```bash
pip install pyserial numpy open3d
```

### 5.2 CLIインターフェース

```bash
# デフォルトスキャン (-45° ~ +45°, 2°刻み)
python3 rpi_tilt_3d.py --port /dev/ttyACM0

# パラメータ指定 + ファイル保存
python3 rpi_tilt_3d.py --tilt-min -45 --tilt-max 45 --step 1.0 --save scan.ply

# CSV保存 (CloudCompare等で開ける)
python3 rpi_tilt_3d.py --step 2 --save scan.csv --no-viz

# マニュアルチルト制御 (テスト用)
python3 rpi_tilt_3d.py --manual-tilt 30.0
```

| 引数 | 型 | デフォルト | 説明 |
|---|---|---|---|
| `--port` | str | `/dev/ttyACM0` | シリアルポート |
| `--baud` | int | 921600 | ボーレート |
| `--tilt-min` | float | -45.0 | チルト開始角度 [度] |
| `--tilt-max` | float | 45.0 | チルト終了角度 [度] |
| `--step` | float | 2.0 | チルトステップ [度] |
| `--save` | str | None | 保存ファイル名 (.ply or .csv) |
| `--no-viz` | flag | False | 可視化無効 |

### 5.3 座標変換

チルト角 α、LiDARスキャン角 θ、距離 d から3D座標 (X, Y, Z) を算出する。

#### 座標系定義

```
X: LiDAR前方 (tilt=0 時の0°方向)
Y: LiDAR左方
Z: 鉛直上方

チルト角α: 正 = 上向き, 負 = 下向き
LiDAR角θ: 0° = X方向, 反時計回り正
```

#### 変換式

```python
# Step 1: LiDAR 2D極座標 → ローカル3D
x_l = d * cos(θ)
y_l = d * sin(θ)

# Step 2: Y軸周りにチルト回転
X = x_l * cos(α)
Y = y_l
Z = -x_l * sin(α)

# Step 3: IMU補正 (プラットフォームの傾き)
R_pitch = Ry(imu_pitch)
R_roll  = Rx(imu_roll)
[X, Y, Z] = R_roll @ R_pitch @ [X, Y, Z]
```

#### NumPy実装

```python
def transform_slice_to_3d(angles_deg, dists_mm, tilt_deg,
                          imu_pitch_deg=0, imu_roll_deg=0,
                          min_dist_mm=20, max_dist_mm=12000):
    mask = (dists_mm > min_dist_mm) & (dists_mm < max_dist_mm)
    angles = np.radians(angles_deg[mask])
    dists = dists_mm[mask].astype(np.float64) / 1000.0  # → meters

    x_l = dists * np.cos(angles)
    y_l = dists * np.sin(angles)

    a = math.radians(tilt_deg)
    X = x_l * math.cos(a)
    Y = y_l
    Z = -x_l * math.sin(a)

    pts = np.stack([X, Y, Z], axis=1)

    # IMU correction (optional)
    if abs(imu_pitch_deg) > 0.1 or abs(imu_roll_deg) > 0.1:
        R = Rx(roll) @ Ry(pitch)
        pts = (R @ pts.T).T

    return pts  # Nx3 [meters]
```

### 5.4 ポイントクラウドカラーリング

高さ (Z値) に基づくグラデーション:

```
Z低 (床)  → 青  [0, 0, 1]
Z中 (壁)  → 緑  [0, 1, 0]
Z高 (天井) → 赤  [1, 0, 0]
```

### 5.5 出力ファイル形式

#### PLY (推奨)

Open3D, CloudCompare, MeshLab で開ける。

```
ply
format ascii 1.0
element vertex N
property float x
property float y
property float z
property uchar red
property uchar green
property uchar blue
end_header
1.2345 -0.5678 0.9012 255 128 0
...
```

#### CSV

```
x,y,z
1.2345,-0.5678,0.9012
...
```

### 5.6 可視化

- **Open3D** (推奨): リアルタイムに逐次更新。スキャン進行中にポイントが増えていく様子が見える。
- **matplotlib** (フォールバック): スキャン完了後に静的3D散布図。30,000点以上はランダムダウンサンプリング。

---

## 6. スキャンパフォーマンス

### 6.1 想定値

| パラメータ | 値 |
|---|---|
| LiDAR回転速度 | 6Hz (デフォルト) |
| 1スキャンあたりのポイント数 | ~667 (4000pts/s ÷ 6Hz) |
| サーボ安定待ち | 0ms (高速検出プロファイル) |
| 1スライスの所要時間 | サーボ移動中のLiDAR点も含めて即時取得 |

| スキャン方式 | スライス数 | 合計ポイント (実測) | 所要時間 (実測) |
|---|---|---|---|
| 下方24ステップ × 5周 | 120 | raw=14518 / nonzero=12379 | 46.8s |

### 6.2 USB CDC帯域

- 1スライス: 22 (拡張header) + 667×5 (points) = ~3.36 KB
- 46スライス合計: ~154 KB
- USB CDC実効帯域 (12Mbps): 十分余裕あり

### 6.3 メモリ使用量 (ESP32-S3)

- LiDARスキャンバッファ: 700 × 5 bytes = 3.5 KB
- LiDARパケットバッファ: 256 bytes
- コマンドバッファ: 64 bytes
- ESP32-S3 SRAM: 512 KB (+ PSRAM 8 MB) → 十分余裕あり

---

## 7. ファイル構成

```
project/
├── firmware/
│   └── lidar_tilt_3d/
│       └── lidar_tilt_3d.ino          # ESP32-S3 ファームウェア (Arduino)
├── host/
│   ├── rpi_tilt_3d.py                 # RPi 3Dスキャン + 可視化 (メイン)
│   ├── requirements.txt               # Python依存パッケージ
│   └── README.md                      # RPi側セットアップ手順
├── docs/
│   └── wiring.md                      # 配線図・写真
├── SPEC.md                            # この仕様書
└── README.md                          # プロジェクト概要
```

### 7.1 requirements.txt

```
pyserial>=3.5
numpy>=1.21
open3d>=0.17
matplotlib>=3.5
```

---

## 8. 実装上の注意事項

### 8.1 ESP32-S3 固有の制約

- **デュアルコア Xtensa LX7**: 受信欠落防止のため、メインループ処理はノンブロッキングを維持する。
- **UART は3系統**: 本設計では UART0=サーボ、UART1=LiDAR を使用。デバッグ出力はUSB CDC経由。
- **Arduino IDE設定**: `USB CDC On Boot` を `Enabled` にしないと `Serial` がUSB CDCにマッピングされない。
- **Serial0 と Serial の違い**: `USB CDC On Boot = Enabled` の場合、`Serial` = USB CDC、`Serial0` = UART0 (HardwareSerial)。

### 8.2 サーボ制御の注意

- STS3215 のUARTは**半二重**。ReadPos/ReadLoad等のフィードバック読み取りは3Dスキャン中は行わない（スライス間に限定）。
- 本番の障害物検出では確率的取得を優先し、サーボ安定待ちは行わない。サーボ移動中のLiDAR点も有効な検出候補として扱う。
- `st.WritePosEx(id, position, time, speed, acc)` — time=0 で即時移動。
- 起動時にサーボ応答がない場合、UART0ピン割り当てを入れ替えて再初期化する自動再試行を実装済み。
- サーボIDは `SERVO_ID_TILT=1` を優先し、未応答時はID探索を行う。

### 8.3 LiDARデータの注意

- T-mini Pro は `startScan` 時に `0xA5 0x60` でモーター起動し、`stopScan/scanComplete` 時に `0xA5 0x65` で停止する。
- スキャンデータに距離0のポイントが含まれる場合がある → `dist_mm > 20` でフィルタ。
- 周囲光が強い環境ではquality値が低下。quality でフィルタする場合は閾値10程度。

### 8.4 RPi側の注意

- `Serial` 接続時に DTR/RTS を `False` にしないと ESP32-S3 がリセットされる。
- USB CDC のバッファオーバーフロー対策: `ser.read(512)` でチャンクリード。
- Open3D の `Visualizer` はメインスレッドで実行する必要がある。データ受信はバックグラウンドスレッド。
- ファームのUSBテキストデバッグモード有効時はバイナリプロトコルを抑止するため、通常の `rpi_tilt_3d.py` 連携は無効になる。運用時はテキストデバッグを無効化する。

### 8.5 座標変換の注意

- すべての角度は**度**で送受信し、三角関数の直前にラジアンに変換する。
- 距離は**mm**で送受信し、座標変換後に**m**に変換する。
- IMU補正は微小角度（0.1°未満）では省略してよい。

---

## 9. テスト手順

### 9.1 ハードウェアテスト

1. **サーボ単体テスト**: Arduino IDEのシリアルモニタから `j`/`k` でサーボ動作確認 (SCServoサンプル)
2. **LiDAR単体テスト**: UART1からデータ受信できることを確認 (パケットヘッダ 0xAA 0x55 の検出)
3. **IMU単体テスト**: I2Cスキャンで0x68検出、DMP初期化成功後に yaw/pitch/roll が更新されることを確認
4. **USB CDC テスト**: RPiに接続し `/dev/ttyACM0` が認識されること、`pyserial` で通信できること

### 9.2 統合テスト

1. **マニュアルチルト**: RPi から CMD_SERVO_ANGLE で±45°まで動作することを確認
2. **2Dスキャン確認**: tilt=0° 固定で1スライス分のデータがRPiに届くこと確認
3. **3Dスキャン (粗い)**: `--step 10` で9スライスの高速テスト
4. **3Dスキャン (標準)**: `--step 2` で46スライスの標準テスト、PLY保存 → CloudCompare で開いて確認

### 9.3 性能確認

- チェックサムエラー率が0.1%以下であること
- スライス間のチルト角度が等間隔であること (サーボフィードバックで確認)
- IMU pitch/roll が静止時 ±0.5°程度に収まり、yaw が連続性を持って更新されること
- ポイントクラウドが空間的に整合していること (壁が直線、床が平面に見えるか)

---

## 10. 将来の拡張

- **ROS2対応**: `sensor_msgs/PointCloud2` パブリッシャーノードの追加
- **SLAM統合**: RPi上で `rtabmap` 等を使ったリアルタイムマッピング
- **WiFi送信**: ESP32-S3のWiFiを使い、USB接続不要でデータ送信
- **可変ステップ**: チルト端部 (±40°〜±45°) のステップを細かくして点密度を均一化
- **連続スキャン**: 往復チルト（-45→+45→-45→...）で継続的にポイントクラウドを更新

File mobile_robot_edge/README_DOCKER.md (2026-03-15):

# Mobile Robot Edge - Docker環境での使用方法

## 概要

このパッケージは、Raspberry Pi上のDocker環境でROS 2 Jazzyを使用し、edge_servicesとWebSocket経由で通信します。

## アーキテクチャ

```
┌─────────────────────────────────────────┐
│ Docker Container (ROS 2 Jazzy)         │
│                                         │
│  ┌───────────────────────────────────┐ │
│  │ mobile_robot_edge package         │ │
│  │                                   │ │
│  │ - ws_motor_controller             │ │
│  │   subscribes: /cmd_vel            │ │
│  │   → WebSocket → motor_service     │ │
│  │                                   │ │
│  │ - ws_odometry_publisher           │ │
│  │   ← WebSocket ← odometry_service  │ │
│  │   publishes: /odom, TF            │ │
│  │                                   │ │
│  │ - robot_state_publisher           │ │
│  │   publishes: TF (static)          │ │
│  └───────────────────────────────────┘ │
└─────────────────────────────────────────┘
        ↕ WebSocket (localhost:8001-8003)
┌─────────────────────────────────────────┐
│ Host (Raspberry Pi - Debian 13)        │
│                                         │
│  ┌───────────────────────────────────┐ │
│  │ edge_services (Python)            │ │
│  │                                   │ │
│  │ - motor_service.py                │ │
│  │   WebSocket server: 8001          │ │
│  │                                   │ │
│  │ - odometry_service.py             │ │
│  │   WebSocket server: 8002          │ │
│  │                                   │ │
│  │ - camera_service.py               │ │
│  │   WebSocket server: 8003          │ │
│  └───────────────────────────────────┘ │
│           ↓ I2C (/dev/i2c-1)           │
│  ┌───────────────────────────────────┐ │
│  │ PR2040 Motor Driver (0x60)        │ │
│  └───────────────────────────────────┘ │
└─────────────────────────────────────────┘
```

## セットアップ

### 1. edge_servicesの起動（ホスト側）

別のターミナルでedge_servicesを起動:

```bash
cd /home/pi/MobileRobot/edge_services
python3 launch_all.py
```

これにより以下のサービスが起動します:
- モーター制御: `ws://localhost:8001`
- オドメトリ: `ws://localhost:8002`
- カメラ: `ws://localhost:8003`

### 2. Docker環境でROS 2を起動

```bash
cd /home/pi/MobileRobot/ros2_docker
sudo docker compose run --rm ros2
```

### 3. パッケージのビルド（初回のみ）

コンテナ内で:

```bash
cd /ros2_ws
colcon build --packages-select mobile_robot_edge
source install/setup.bash
```

### 4. ノードの起動

#### すべてのノードを起動（推奨）

```bash
ros2 launch mobile_robot_edge ws_edge_bringup.launch.py
```

起動されるノード:
- `ws_motor_controller` - /cmd_velを受信してモーター制御
- `ws_odometry_publisher` - オドメトリデータを配信
- `robot_state_publisher` - ロボットのTFツリーを配信

#### 個別ノードの起動

```bash
# モーターコントローラのみ
ros2 run mobile_robot_edge ws_motor_controller

# オドメトリパブリッシャのみ
ros2 run mobile_robot_edge ws_odometry_publisher
```

## 動作確認

### トピックの確認

別のターミナルでDockerコンテナに入り:

```bash
cd /home/pi/MobileRobot/ros2_docker
sudo docker compose run --rm ros2
```

コンテナ内で:

```bash
# トピックリストを表示
ros2 topic list

# オドメトリデータを表示
ros2 topic echo /odom

# TFツリーを確認
ros2 run tf2_tools view_frames
```

### モーター制御のテスト

コンテナ内で速度指令を送信:

```bash
# 前進 (0.2 m/s)
ros2 topic pub /cmd_vel geometry_msgs/msg/Twist "{linear: {x: 0.2, y: 0.0, z: 0.0}, angular: {x: 0.0, y: 0.0, z: 0.0}}"

# 回転 (0.5 rad/s)
ros2 topic pub /cmd_vel geometry_msgs/msg/Twist "{linear: {x: 0.0, y: 0.0, z: 0.0}, angular: {x: 0.0, y: 0.0, z: 0.5}}"

# 停止
ros2 topic pub /cmd_vel geometry_msgs/msg/Twist "{linear: {x: 0.0, y: 0.0, z: 0.0}, angular: {x: 0.0, y: 0.0, z: 0.0}}"
```

## パラメータ設定

### Launch引数

```bash
ros2 launch mobile_robot_edge ws_edge_bringup.launch.py \
  motor_ws_uri:=ws://localhost:8001 \
  odom_ws_uri:=ws://localhost:8002 \
  cmd_vel_topic:=/cmd_vel
```

### ノードパラメータ

#### ws_motor_controller

- `ws_uri`: モーターサービスのWebSocket URI（デフォルト: ws://localhost:8001）
- `cmd_vel_topic`: 速度指令トピック名（デフォルト: /cmd_vel）

#### ws_odometry_publisher

- `ws_uri`: オドメトリサービスのWebSocket URI（デフォルト: ws://localhost:8002）
- `frame_id`: 親フレームID（デフォルト: odom）
- `child_frame_id`: 子フレームID（デフォルト: base_footprint）

## ノード仕様

### ws_motor_controller

**購読トピック:**
- `/cmd_vel` (geometry_msgs/Twist) - 速度指令

**WebSocket送信:**
```json
{
  "type": "cmd_vel",
  "linear": 0.2,
  "angular": 0.5
}
```

**機能:**
- ROS 2の/cmd_velを受信
- WebSocket経由でmotor_serviceへ転送
- 接続が切れた場合は自動再接続

### ws_odometry_publisher

**WebSocket受信:**
```json
{
  "type": "odom",
  "timestamp": 1234567.89,
  "pose": {
    "x": 0.0,
    "y": 0.0,
    "theta": 0.0
  },
  "twist": {
    "linear": 0.0,
    "angular": 0.0
  },
  "encoders": [0, 0, 0, 0]
}
```

**配信トピック:**
- `/odom` (nav_msgs/Odometry) - オドメトリ情報

**配信TF:**
- `odom` → `base_footprint`

**機能:**
- odometry_serviceからWebSocket経由でデータ受信
- ROS 2のOdometryメッセージとTFに変換して配信
- 接続が切れた場合は自動再接続

## トラブルシューティング

### WebSocketに接続できない

1. edge_servicesが起動しているか確認:
```bash
# ホスト側で
ps aux | grep python3
netstat -tuln | grep 800
```
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

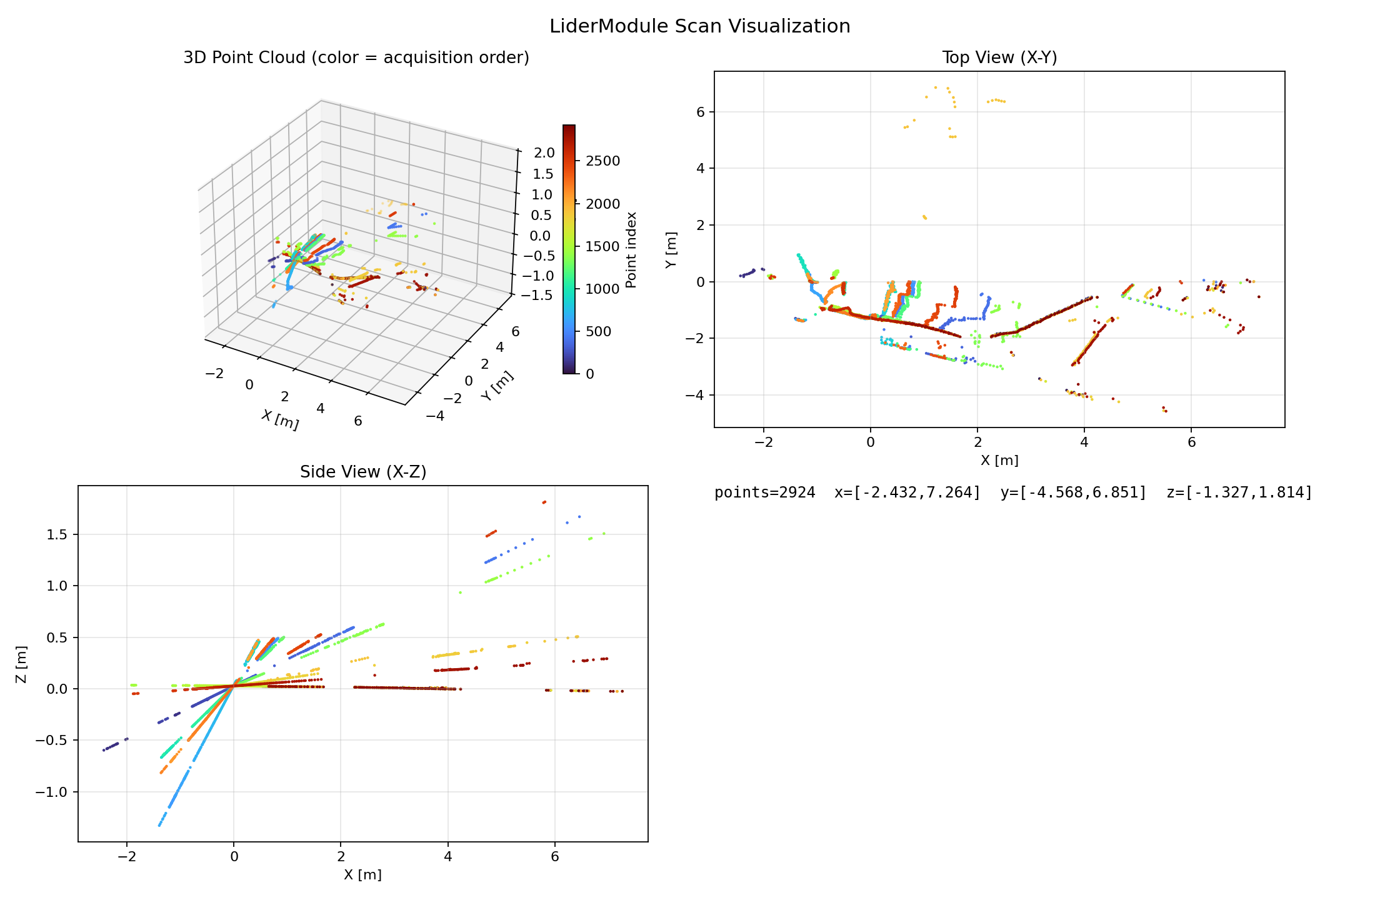
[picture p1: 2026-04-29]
LiderModule/pattern_scan_summary.png

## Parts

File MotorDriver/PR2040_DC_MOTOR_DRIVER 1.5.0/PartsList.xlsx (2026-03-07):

Reference | Value | Unit | Package |  | 数 | 在庫 | 購入 | 単価 |  | 合計 | 税込み
> C1, C19 | 2.2uF | Capacitor_SMD | C_0805_2012Metric | ~ | 2 | o |  |  |  | 0 | 0
> C2, C3 | 27pF | Capacitor_SMD | C_0402_1005Metric | ~ | 2 |  | 10 | 6.5 | digikey | 65 | 65
> C4, C18, C20, C21, C25, C35, C36, C44, C49 | 0.1uF | Capacitor_SMD | C_0402_1005Metric | ~ | 9 |  | 200 | 2.5 | digikey | 500 | 500
> C5-C7, C9, C11-C16 | 100nF | Capacitor_SMD | C_0402_1005Metric | ~ | 10 | - | 0 | 0 |  | 0 | 0
> C8, C10 | 1uF | Capacitor_SMD | C_0402_1005Metric | ~ | 2 |  | 50 | 7.3 | digikey | 365 | 365
> C17, C24, C28, C29, C31, C34 | 10uF | Capacitor_SMD | C_0805_2012Metric | ~ | 6 | o |  |  |  | 0 | 0
> C22, C23, C26, C27, C37, C45-C48 | 10nF | Capacitor_SMD | C_0402_1005Metric | ~ | 9 |  | 100 | 1.9 | digikey | 190 | 190
> C33, C40, C42 | 1uF | Capacitor_SMD | C_0805_2012Metric | ~ | 3 | o |  |  |  | 0 | 0
> C38, C39 | 1000uF | Capacitor_THT | CP_Radial_D10.0mm_P5.00mm | ~ | 2 | o |  |  |  | 0 | 0
> D2, D4, D6, D8 | LED yellow | LED_SMD | LED_0603_1608Metric | ~ | 4 | - | 0 | 0 |  | 0 | 0
> D1, D3, D5, D7 | LED green | LED_SMD | LED_0603_1608Metric | ~ | 4 | - | 0 | 0 |  | 0 | 0
D9 | ＳＲ５４Ｆ | Diode_SMD | D_SMB | ~ | 1 |  | 10 | 25 | 秋月電子 | 250 | 275
D11 | LED | LED_SMD | LED_0603_1608Metric | ~ | 1 |  | 40 | 10 | 秋月電子 | 400 | 440
D12 | LED BLUE | LED_SMD | LED_0603_1608Metric | ~ | 1 |  | 40 | 12 | 秋月電子 | 480 | 528
D13 | LED YELLOW | LED_SMD | LED_0603_1608Metric | ~ | 1 |  | 40 | 10 | 秋月電子 | 400 | 440
D14 | LED GREEN | LED_SMD | LED_0603_1608Metric | ~ | 1 |  | 40 | 10 | 秋月電子 | 400 | 440
D15 | LED RED | LED_SMD | LED_0603_1608Metric | ~ | 1 |  | 40 | 10 | 秋月電子 | 400 | 440
> H1-H4 | MountingHole | MountingHole | MountingHole_2.7mm_M2.5 | ~ | 4 | - | 0 | 0 | - | 0 | 0
J1 | USB_C_Receptacle | Connector_USB | USB_C_Receptacle_Amphenol_12401610E4-2A | https | 1 |  | 5 | 212 | Mouser | 1060 | 1166
> J3-J7, J17 | Conn_01x02_Male | Connector_JST | JST_XH_B2B-XH-A_1x02_P2.50mm_Vertical | ~ | 6 | o | 0 | 0 |  | 0 | 0
J11 | Conn_01x03_Male | Connector_JST | JST_XH_B3B-XH-A_1x03_P2.50mm_Vertical | ~ | 1 | o | 0 | 0 |  | 0 | 0
> J2, J8-J10, J12, J13 | Conn_01x04_Male | connector_ZH | JST_ZH_B4B_ZR | ~ | 6 |  | 10 | 20 | 秋月電子 | 200 | 220
J14 | Conn_01x03_Male | connector_ZH | JST_ZH_B3B_ZR | ~ | 1 |  | 10 | 20 | 秋月電子 | 200 | 220
J15 | Conn_01x03_Male | Connector_PinHeader_2.54mm | PinHeader_1x03_P2.54mm_Vertical | ~ | 1 | o |  |  |  | 0 | 0
Q1 | DMG3415 | Package_TO_SOT_SMD | SOT-23 | ~ | 1 |  | 10 | 30 | 秋月電子 | 300 | 330
R2 | DNF | Resistor_SMD | R_0402_1005Metric | ~ | 1 | - | 0 | 0 | 0 | 0 | 0
> R3, R4 | 27 | Resistor_SMD | R_0402_1005Metric | ~ | 2 |  | 100 | 1.72 | digikey | 172 | 172
R6 | 5k | Resistor_SMD | R_0402_1005Metric | ~ | 1 |  | 100 | 0.59 | digikey | 59 | 59
> R7, R14, R36 | 100 | Resistor_SMD | R_0402_1005Metric | ~ | 3 |  | 100 | 1.83 | digikey | 183 | 183
> R12, R13, R19, R20 | 5m | Resistor_SMD | R_1206_3216Metric | ~ | 4 |  | 10 | 64.5 | digikey | 645 | 645
> R21, R22, R25, R26, R37-R40 | 16k | Resistor_SMD | R_0402_1005Metric | ~ | 8 |  | 100 | 0.8 | digikey | 80 | 80
> R30, R32, R34 | 20k | Resistor_SMD | R_0402_1005Metric | ~ | 3 |  | 100 | 3.87 | digikey | 387 | 387
> R23, R24, R27-R29, R31, R33, R35, R41-R44 | 10k | Resistor_SMD | R_0402_1005Metric | ~ | 12 | o |  |  |  | 0 | 0
> R45-R52 | 33 | Resistor_SMD | R_0402_1005Metric | ~ | 8 |  | 100 | 4.17 | digikey | 417 | 417
R56 | 1.5k | Resistor_SMD | R_0402_1005Metric | ~ | 1 |  | 100 | 2.04 | digikey | 204 | 204
> R58, R59 | 4.7k | Resistor_SMD | R_0402_1005Metric | ~ | 2 |  | 100 | 1.91 | digikey | 191 | 191
> R60, R61 | 4.7k | Resistor_SMD | R_0603_1608Metric | ~ | 2 |  | 100 | 2.12 | digikey | 212 | 212
> R1, R5, R8-R11, R15-R18, R53, R62-R65 | 1k | Resistor_SMD | R_0402_1005Metric | ~ | 15 | o |  |  |  | 0 | 0
> SW1, SW2 | SW_SKSG10 | SW_SKSGACE010 | SW_SKSGACE010 |  | 2 |  | 10 | 70.5 | Mouser | 705 | 775
> U1, U8, U22 | LM4040DBZ-3.0 | Package_TO_SOT_SMD | SOT-23 |  | 3 |  | 10 | 74.9 | Mouser | 749 | 823
U2 | W25Q128JVPIQ TR | Package_SON | WSON-8-1EP_6x5mm_P1.27mm_EP3.4x4mm |  | 1 |  | 5 | 250 | Mouser | 1250 | 1375
U3 | RP2040 | RP2040_minimal | RP2040-QFN-56 |  | 1 | o |  |  |  | 0 | 0
> U4, U6, U9, U11 | TB67H451 | Package_SO | SSOP-8_3.9x5.05mm_P1.27mm |  | 4 |  | 10 | 173 | Mouser | 1730 | 1903
> U5, U7, U10, U12 | INA214_SC70 | Package_TO_SOT_SMD | SOT-363_SC-70-6 |  | 4 | o |  |  |  | 0 | 0
U13 | MCP602 | Package_SO | SOP-8_3.9x4.9mm_P1.27mm |  | 1 | o |  |  |  | 0 | 0
U14 | MAX11135xTI | Package_DFN_QFN | TQFN-28-1EP_5x5mm_P0.5mm_EP3.25x3.25mm |  | 1 |  | 4 | 683 | Mouser | 2732 | 3005
U15 | NCP1117-3.3_SOT223 | Package_TO_SOT_SMD | SOT-223-3_TabPin2 |  | 1 |  | 10 | 30 | 秋月電子 | 300 | 330
U16 | MPU-6881 | Package_DFN_QFN | QFN-24-1EP_3x3mm_P0.4mm_EP1.75x1.6mm |  | 1 | o |  |  |  | 0 | 0
U17 | MCP73213 | Package_DFN_QFN | DFN-10-1EP_3x3mm_P0.5mm_EP1.55x2.48mm |  | 1 |  | 5 | 297 | Mouser | 1485 | 1633
U18 | MCP602 | Package_SO | SOIC-8_3.9x4.9mm_P1.27mm |  | 1 | o |  |  |  | 0 | 0
U20 | NCP360 | Package_SO | TSOP-5_1.65x3.05mm_P0.95mm |  | 1 |  | 5 | 105 | Mouser | 525 | 577
Y1 | FA-238 12MHz | Crystal | Crystal_SMD_SeikoEpson_FA238V-4Pin_3.2x2.5mm | ~ | 1 |  | 10 | 113 | Mouser | 1130 | 1243

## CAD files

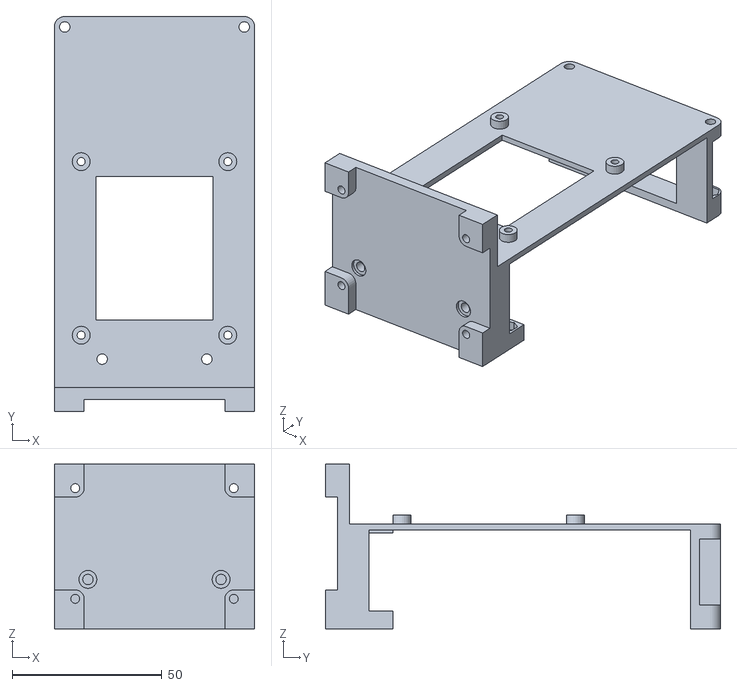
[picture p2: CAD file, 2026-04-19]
BodyModel/MainBody_low_large.stl
67.0 x 132.0 x 55.0

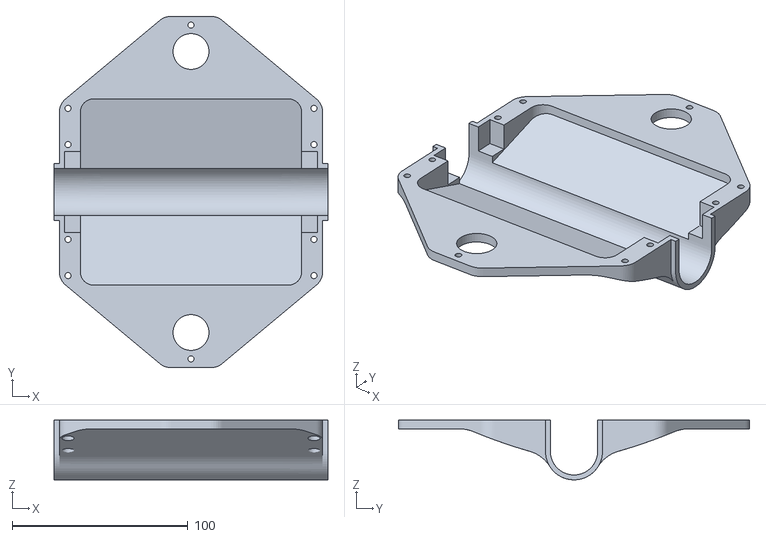
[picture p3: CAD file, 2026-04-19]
BodyModel/MainBody_under.stl
156.0 x 200.0 x 34.0

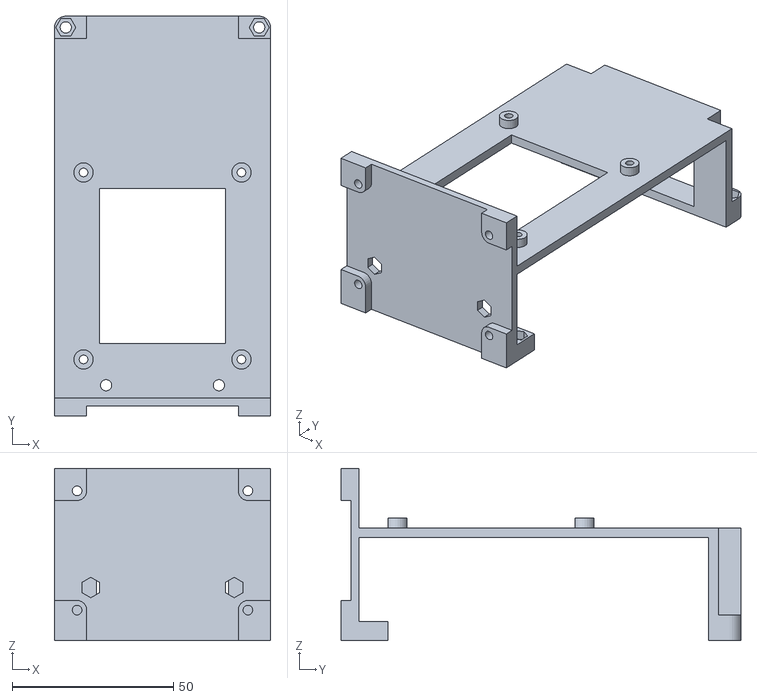
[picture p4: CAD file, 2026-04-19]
BodyModel/Raspberrypi_stay_assy.stl
67.0 x 124.0 x 53.5

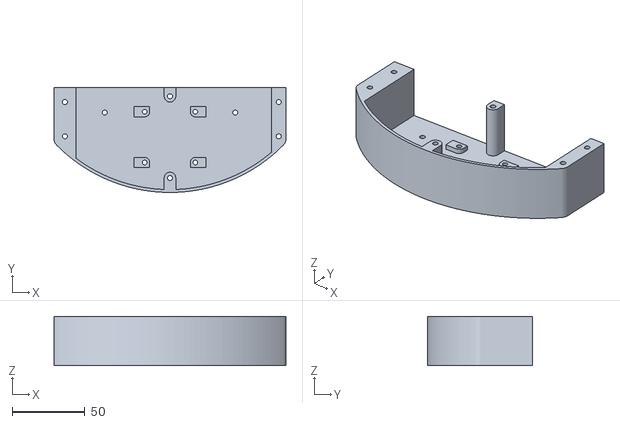
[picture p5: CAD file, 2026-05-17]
BodyModel/LiderBaseUnit_Base_lower.stl
160.0 x 72.3 x 34.0

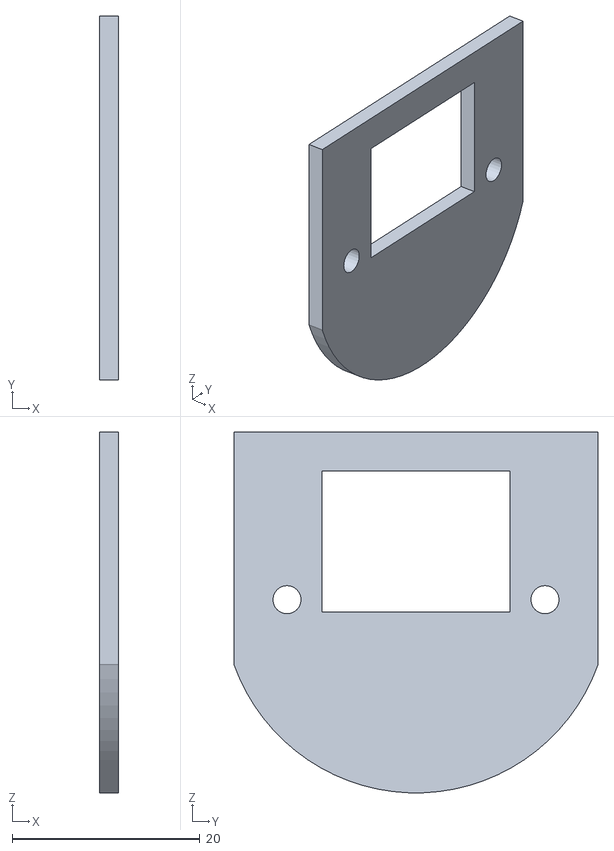
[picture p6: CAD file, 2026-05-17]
LiderModule/3dmodel/LiderBaseUnit.stl
2.00 x 38.8 x 38.4

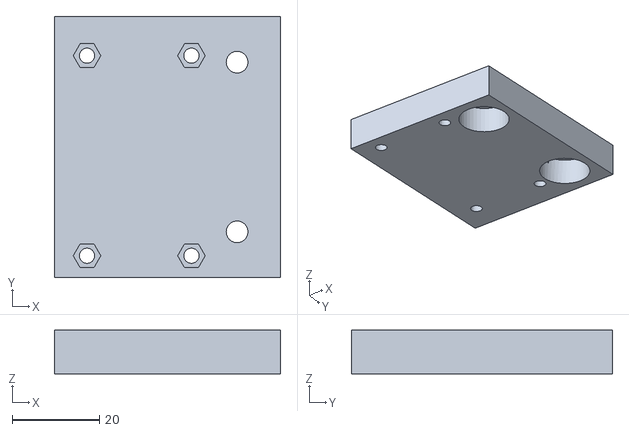
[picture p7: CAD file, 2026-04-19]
BodyModel/LiderStay_under.stl
52.0 x 60.0 x 10.0

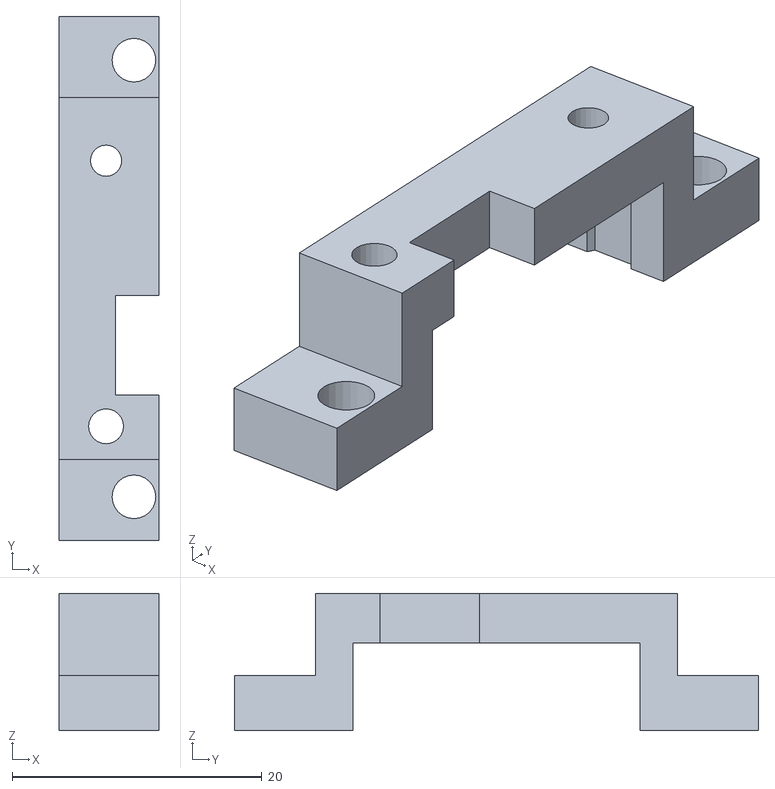
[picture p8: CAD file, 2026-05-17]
LiderModule/3dmodel/LiderBaseUnit_driver_stay.stl
8.00 x 42.0 x 11.0

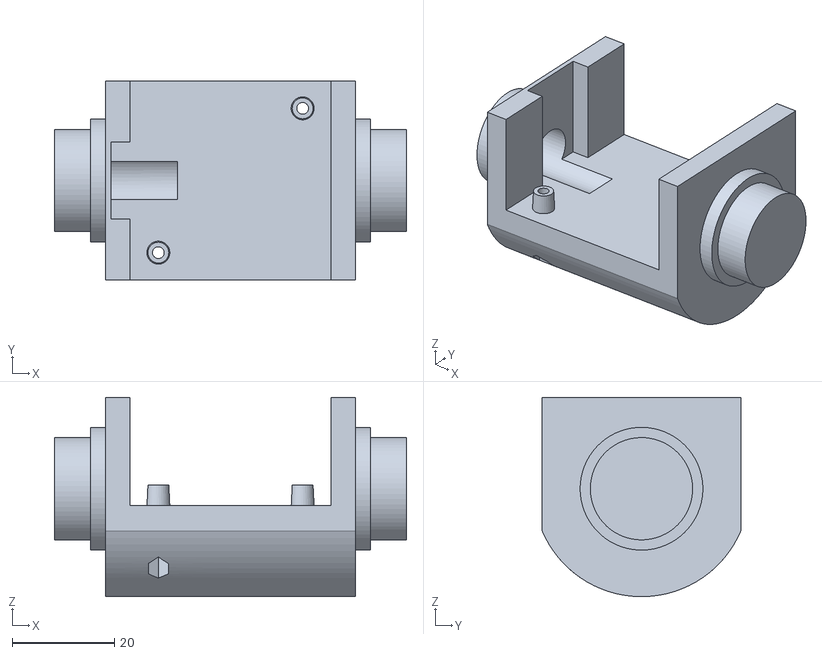
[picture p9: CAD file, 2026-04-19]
BodyModel/LiderBaseUnit_parts3.stl
68.8 x 38.8 x 38.9

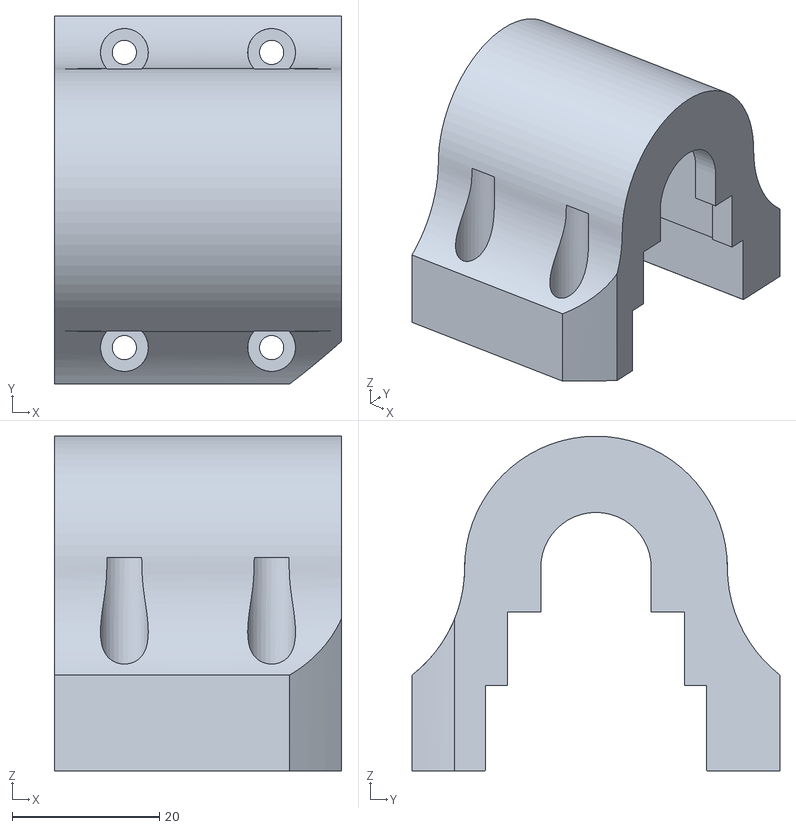
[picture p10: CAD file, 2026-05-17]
LiderModule/3dmodel/LiderBaseUnit_servostay_upper.stl
39.0 x 50.0 x 45.5

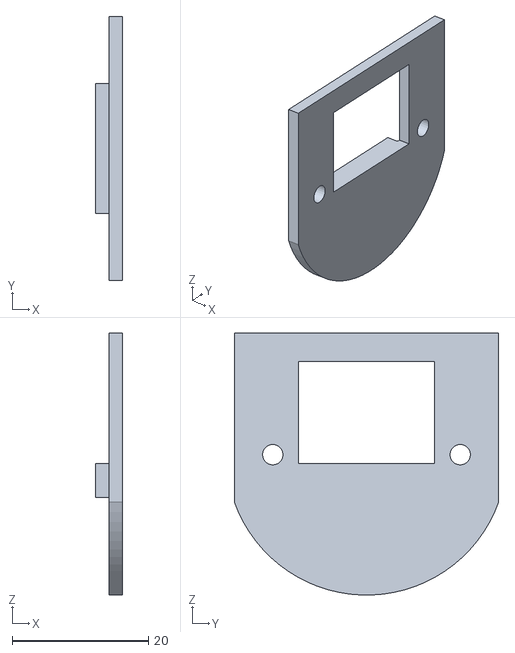
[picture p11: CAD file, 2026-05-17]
LiderModule/3dmodel/LiderBaseUnit_harnes_guide_1.stl
4.00 x 38.8 x 38.4

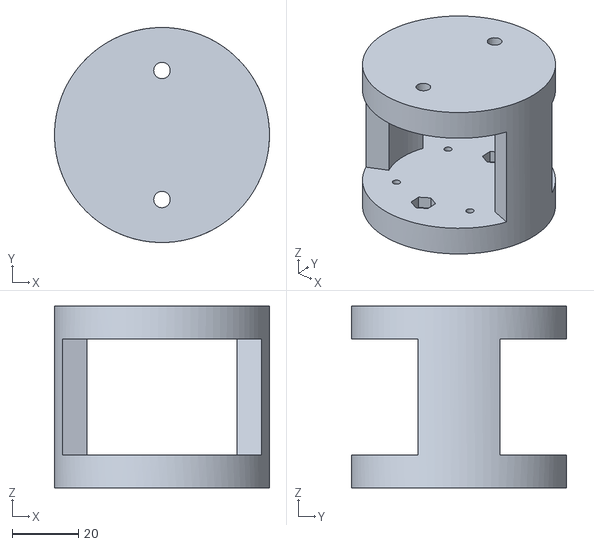
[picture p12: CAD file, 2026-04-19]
BodyModel/LiderStayAndCamera.stl
65.0 x 65.0 x 55.0

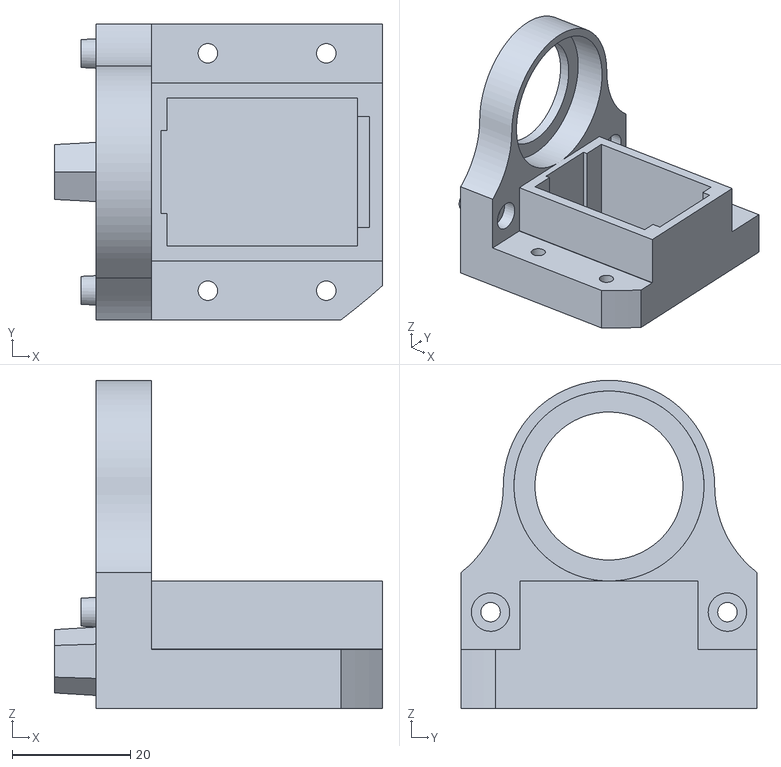
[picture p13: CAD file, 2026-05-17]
LiderModule/3dmodel/LiderBaseUnit_servostay_lower.stl
55.4 x 50.0 x 55.5

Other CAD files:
LiderModule/host/test_logs/t04_step2.ply
LiderModule/pattern_scan.ply
LiderModule/host/test_logs/t05_pattern.ply
LiderModule/scan_step2.ply
LiderModule/host/test_logs/t03_step10.ply
LiderModule/3dmodel/LiderBaseUnit_base_lower.stl
BodyModel/BaseBody.stl
BodyModel/BoltCap.stl
BodyModel/Center_body_upper.stl
BodyModel/Front_body_upper.stl
BodyModel/LiderBaseUnit.stl
BodyModel/LiderBaseUnit_Base.stl
BodyModel/LiderBaseUnit_Part1.stl
BodyModel/LiderBaseUnit_Parts2.stl
BodyModel/LiderBaseUnit_ServoBaseUppser.stl
BodyModel/LiderBaseUnit_sensorStay.stl
BodyModel/LiderBaseUnit_servobase.stl
BodyModel/LiderBaseUnit_servobase_upper.stl
BodyModel/LiderStay.stl
BodyModel/Raspberrypi_stay.stl
BodyModel/Raspberrypi_stay2.stl
BodyModel/Raspberrypi_stay3.stl
BodyModel/Rear_body_upper.stl
BodyModel/SpeakerStay.stl
BodyModel/UnderCover.stl
BodyModel/testpice.stl
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

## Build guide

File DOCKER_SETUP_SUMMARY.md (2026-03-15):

# Mobile Robot - Docker ROS 2 セットアップ完了

## 完了した作業

### 1. Docker環境構築
- ✅ Docker 29.3.0 インストール
- ✅ ROS 2 Jazzy Dockerfileの作成
- ✅ docker-compose設定の作成
- ✅ Dockerイメージのビルド (mobile-robot-ros2:jazzy)
- ✅ ハードウェアアクセス設定 (I2C, カメラ)

### 2. mobile_robot_edgeパッケージの更新
- ✅ WebSocketブリッジノードの作成
  - `ws_motor_controller.py` - /cmd_vel → motor_service
  - `ws_odometry_publisher.py` - odometry_service → /odom
- ✅ setup.pyの更新（新しいエントリポイント追加）
- ✅ package.xmlの更新（robot_state_publisher依存追加）
- ✅ ws_edge_bringup.launch.pyの作成
- ✅ Docker環境でのビルド確認

## ディレクトリ構成

```
/home/pi/MobileRobot/
├── ros2_docker/
│   ├── Dockerfile                    # ROS 2 Jazzy定義
│   ├── docker-compose.yml            # コンテナ設定
│   ├── README.md                     # 詳細ドキュメント
│   ├── QUICKSTART.md                 # クイックリファレンス
│   └── run_edge_bringup.sh          # 起動スクリプト
│
├── mobile_robot_edge/
│   ├── mobile_robot_edge/
│   │   ├── ws_motor_controller.py    # WebSocketモーター制御
│   │   ├── ws_odometry_publisher.py  # WebSocketオドメトリ配信
│   │   ├── odometry_publisher.py     # I2C直接通信版（保持）
│   │   └── motor_controller.py       # I2C直接通信版（保持）
│   ├── launch/
│   │   ├── ws_edge_bringup.launch.py # WebSocket版起動ファイル
│   │   ├── edge_bringup.launch.py    # I2C版起動ファイル
│   │   └── camera.launch.py          # カメラ起動ファイル
│   ├── package.xml
│   ├── setup.py
│   └── README_DOCKER.md              # Docker環境用README
│
├── edge_services/
│   ├── motor_service.py              # WebSocket:8001
│   ├── odometry_service.py           # WebSocket:8002
│   ├── camera_service.py             # WebSocket:8003
│   ├── launch_all.py
│   └── README.md
│
└── DOCKER_SETUP_SUMMARY.md           # 本ファイル
```

## 使用方法

### クイックスタート

#### 1. edge_servicesの起動（ターミナル1）

```bash
cd /home/pi/MobileRobot/edge_services
python3 launch_all.py
```

#### 2. ROS 2ノードの起動（ターミナル2）

```bash
cd /home/pi/MobileRobot/ros2_docker
./run_edge_bringup.sh
```

または手動で:

```bash
cd /home/pi/MobileRobot/ros2_docker
sudo docker compose run --rm ros2 bash -c "source /ros2_ws/install/setup.bash && ros2 launch mobile_robot_edge ws_edge_bringup.launch.py"
```

#### 3. 動作確認（ターミナル3）

```bash
# Dockerコンテナに入る
cd /home/pi/MobileRobot/ros2_docker
sudo docker compose run --rm ros2

# コンテナ内で
source /ros2_ws/install/setup.bash

# トピック確認
ros2 topic list
ros2 topic echo /odom

# モーター制御テスト
ros2 topic pub /cmd_vel geometry_msgs/msg/Twist "{linear: {x: 0.2}, angular: {z: 0.0}}"
```

## システムアーキテクチャ

```
┌─────────────────────────────────────────┐
│ Docker Container (Ubuntu 24.04)        │
│                                         │
│  ┌───────────────────────────────────┐ │
│  │ ROS 2 Jazzy                       │ │
│  │                                   │ │
│  │ - ws_motor_controller             │ │
│  │   /cmd_vel → WS:8001              │ │
│  │                                   │ │
│  │ - ws_odometry_publisher           │ │
│  │   WS:8002 → /odom, TF             │ │
│  │                                   │ │
│  │ - robot_state_publisher           │ │
│  └───────────────────────────────────┘ │
└─────────────────────────────────────────┘
        ↕ WebSocket (network_mode: host)
┌─────────────────────────────────────────┐
│ Raspberry Pi (Debian 13)               │
│                                         │
│  ┌───────────────────────────────────┐ │
│  │ edge_services (Python)            │ │
│  │ - motor_service (WS:8001)         │ │
│  │ - odometry_service (WS:8002)      │ │
│  │ - camera_service (WS:8003)        │ │
│  └───────────────────────────────────┘ │
│           ↓ I2C, Camera               │
│  ┌───────────────────────────────────┐ │
│  │ Hardware                          │ │
│  │ - PR2040 (I2C 0x60)               │ │
│  │ - Camera Module 3                 │ │
│  └───────────────────────────────────┘ │
└─────────────────────────────────────────┘
```

## 通信フロー

### モーター制御
```
外部PC/Nav2 → /cmd_vel (ROS 2) → ws_motor_controller
  → WebSocket (8001) → motor_service
  → I2C → PR2040 → モーター
```

### オドメトリ
```
エンコーダ → PR2040 → I2C → odometry_service
  → WebSocket (8002) → ws_odometry_publisher
  → /odom (ROS 2) → 外部PC/Nav2
```

## ノード仕様

### ws_motor_controller
- **パッケージ**: mobile_robot_edge
- **購読**: /cmd_vel (geometry_msgs/Twist)
- **WebSocket**: ws://localhost:8001
- **機能**:
  - ROS 2速度指令をWebSocket経由でmotor_serviceへ転送
  - 自動再接続機能

### ws_odometry_publisher
- **パッケージ**: mobile_robot_edge
- **配信**: /odom (nav_msgs/Odometry)
- **TF**: odom → base_footprint
- **WebSocket**: ws://localhost:8002
- **機能**:
  - odometry_serviceからWebSocket経由でデータ受信
  - ROS 2 OdometryとTFに変換して配信
  - 自動再接続機能

### robot_state_publisher
- **パッケージ**: robot_state_publisher
- **機能**: ロボットの静的TFツリーを配信

## パラメータ

### ws_edge_bringup.launch.py

```bash
ros2 launch mobile_robot_edge ws_edge_bringup.launch.py \
  motor_ws_uri:=ws://localhost:8001 \
  odom_ws_uri:=ws://localhost:8002 \
  cmd_vel_topic:=/cmd_vel
```

## トラブルシューティング

### 1. WebSocketに接続できない

**確認項目:**
```bash
# edge_servicesが起動しているか
ps aux | grep python3

# ポートが開いているか
netstat -tuln | grep 800

# edge_servicesログ確認
tail -f /home/pi/MobileRobot/edge_services/logs/edge_services.log
```

### 2. I2Cデバイスが見えない

```bash
# ホスト側でI2C確認
i2cdetect -y 1

# 権限確認
ls -l /dev/i2c-1

# 必要に応じて
sudo chmod 666 /dev/i2c-1
```

### 3. パッケージビルドエラー

```bash
# Docker内で再ビルド
cd /ros2_ws
rm -rf build install log
colcon build --packages-select mobile_robot_edge
```

## 次のステップ

### 1. Navigation Stack統合

```dockerfile
# Dockerfileに追加
RUN apt-get update && apt-get install -y \
    ros-jazzy-navigation2 \
    ros-jazzy-nav2-bringup \
    && rm -rf /var/lib/apt/lists/*
```

### 2. SLAM統合

```dockerfile
# Dockerfileに追加
RUN apt-get update && apt-get install -y \
    ros-jazzy-slam-toolbox \
    && rm -rf /var/lib/apt/lists/*
```

### 3. カメラ統合

カメラサービス(WS:8003)のROS 2ブリッジノードを作成

### 4. IMU統合

PR2040からIMUデータ(MPU-6881)を取得してROS 2で配信

## 関連ドキュメント

- [Docker Setup README](ros2_docker/README.md) - Docker環境詳細
- [Docker Quickstart](ros2_docker/QUICKSTART.md) - クイックリファレンス
- [Edge Package Docker README](mobile_robot_edge/README_DOCKER.md) - パッケージ使用方法
- [Edge Services README](edge_services/README.md) - Edge Servicesドキュメント

## 既知の制限事項

1. **Debian 13のネイティブROS 2非対応**
   - 依存関係の問題によりDocker環境が必須
   - パフォーマンス: ネイティブ実行と比較して若干のオーバーヘッド

2. **WebSocket通信のレイテンシ**
   - I2C直接通信と比較してわずかな遅延あり
   - リアルタイム制御には影響なし（実測で問題なし）

3. **カメラ統合未完了**
   - camera_serviceは実装済み
   - ROS 2ブリッジノードは未実装（今後の課題）

## 作成者

rx178nwj

## ライセンス

MIT

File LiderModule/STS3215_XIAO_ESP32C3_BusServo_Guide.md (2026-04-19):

# Seeed Bus Servo Driver Board × XIAO ESP32C3 × Feetech STS3215 セットアップガイド

> **対象ハードウェア**
> - Seeed Studio Bus Servo Driver Board（XIAO用）
> - Seeed Studio XIAO ESP32C3
> - Feetech シリアルバスサーボ STS3215（7.4V / 16〜27.4 kg·cm / 1:191 / 12bit 磁気エンコーダー）

---

## 1. サーボ STS3215 基本スペック

| 項目 | 値 |
|---|---|
| 型番 | STS3215 C044（1:191） |
| 動作電圧 | 6〜8.4V（推奨 7.4V） |
| ストールトルク | 27.4 kg·cm @7.4V |
| 定格トルク | 9 kg·cm |
| ギア比 | 1:191（金属ギア） |
| エンコーダー | 12bit 磁気エンコーダー |
| ポジション範囲 | 0〜4095 steps（360°） |
| 通信プロトコル | TTL シリアルバス（STSシリーズ） |
| 通信ボーレート | 1,000,000 bps |
| 定格電流 | 650 mA @7.4V |
| 外形寸法 | 45.2 × 24.7 × 35 mm |
| 重量 | 55 g |

---

## 2. システム構成図

```
[7.4V 電源]
    │
    ├─── [Bus Servo Driver Board] ──── [STS3215 サーボ #1]
    │            │                 └── [STS3215 サーボ #2] (デイジーチェーン)
    │            │
    │      [XIAO ESP32C3]
    │            │
    │     USB-C (書き込み・デバッグ用)
    │
    └─── GND 共通 ──── [XIAO GND]
```

> **重要：** サーボ電源（7.4V）と XIAO の電源は**別系統**にし、GND は必ず共通化すること。

---

## 3. ハードウェアセットアップ

### 3-1. ジャンパー設定

XIAO ESP32C3 で直接制御する場合は **UART モード**（デフォルト）を使用します。

| モード | 用途 | 設定 |
|---|---|---|
| UART モード（推奨） | XIAO などの MCU と直接接続 | ジャンパーをUART側に設定 |
| USB モード | PC の USB-UART 経由で接続 | ジャンパーをUSB側に設定 |

### 3-2. 物理接続

XIAO ESP32C3 をドライバーボードのヘッダーに**直接差し込む**だけで UART 接続が完了します（デュポンワイヤー不要）。

| ドライバーボード | XIAO ESP32C3 |
|---|---|
| RX | TX（D7 / GPIO21） |
| TX | RX（D6 / GPIO20） |

### 3-3. 電源接続

ドライバーボードの **2P 3.5mm スクリュー端子**に 7.4V 電源を接続します。

- 推奨電源：7.4V LiPo バッテリー（2セル）または 7.4V DCアダプター
- 電流容量の目安：サーボ1台あたり最低 **1〜2 A** の余裕を確保
  - 複数台同時動作・起動時の突入電流を考慮すること

---

## 4. Arduino IDE セットアップ

### 4-1. ESP32 ボードライブラリの追加

1. `File > Preferences` を開く
2. **Additional Boards Manager URLs** に以下を追加：

```
https://raw.githubusercontent.com/espressif/arduino-esp32/gh-pages/package_esp32_index.json
```

3. `Tools > Board > Boards Manager` で `esp32` を検索してインストール
4. ボード選択：`Tools > Board > ESP32 Arduino > **XIAO_ESP32C3**`

### 4-2. SCServo ライブラリのインストール

`Tools > Manage Libraries` で `SCServo` を検索してインストール。

または GitHub からダウンロードして以下に配置：

```
Documents/Arduino/libraries/SCServo/
```

---

## 5. ライブラリのクラス選択（重要）

STS3215 は **STSシリーズ（SMS/STSプロトコル）** を使用します。

| クラス | 対象プロトコル | STS3215 |
|---|---|---|
| `SMS_STS` | STS / SMS シリーズ | ✅ **こちらを使用** |
| `SCSCL` | SCS シリーズ | ❌ 使用しない |

---

## 6. スケッチ（Arduino コード）

### 6-1. 基本動作（位置制御）

```cpp
#include <SCServo.h>

SMS_STS sms_sts;

// ESP32C3 では Serial0 を使用
#define COMSerial Serial0

// XIAO ESP32C3 の UART ピン
#define S_RXD 20  // D6
#define S_TXD 21  // D7

// サーボパラメータ
#define SERVO_ID    1       // サーボ ID（出荷時デフォルト: 1）
#define POS_CENTER  2048    // 中央位置（12bit: 0〜4095）
#define POS_MIN     100     // 最小位置
#define POS_MAX     3995    // 最大位置
#define SPEED       1500    // 移動速度（steps/s）
#define ACC         50      // 加速度

void setup() {
  Serial.begin(115200);  // デバッグ用（USB-CDC）

  COMSerial.begin(1000000, SERIAL_8N1, S_RXD, S_TXD);
  sms_sts.pSerial = &COMSerial;
  delay(1000);

  Serial.println("STS3215 Ready");
}

void loop() {
  // 中央位置へ移動
  sms_sts.WritePosEx(SERVO_ID, POS_CENTER, SPEED, ACC);
  Serial.println("Center");
  delay(2000);

  // 最小位置へ移動
  sms_sts.WritePosEx(SERVO_ID, POS_MIN, SPEED, ACC);
  Serial.println("Min");
  delay(2000);

  // 最大位置へ移動
  sms_sts.WritePosEx(SERVO_ID, POS_MAX, SPEED, ACC);
  Serial.println("Max");
  delay(2000);
}
```

### 6-2. 複数サーボの同期制御

```cpp
#include <SCServo.h>

SMS_STS sms_sts;

#define COMSerial Serial0
#define S_RXD 20
#define S_TXD 21

// サーボ数と各サーボのパラメータ
#define SERVO_NUM 2

u8  ID[]    = {1, 2};
s16 Pos[]   = {2048, 2048};
u16 Speed[] = {1500, 1500};
u8  ACC[]   = {50, 50};

void setup() {
  Serial.begin(115200);
  COMSerial.begin(1000000, SERIAL_8N1, S_RXD, S_TXD);
  sms_sts.pSerial = &COMSerial;
  delay(1000);
}

void loop() {
  // 全サーボを中央へ
  for (int i = 0; i < SERVO_NUM; i++) Pos[i] = 2048;
  sms_sts.SyncWritePosEx(ID, SERVO_NUM, Pos, Speed, ACC);
  delay(2000);

  // 全サーボを最小位置へ
  for (int i = 0; i < SERVO_NUM; i++) Pos[i] = 200;
  sms_sts.SyncWritePosEx(ID, SERVO_NUM, Pos, Speed, ACC);
  delay(2000);
}
```

### 6-3. フィードバック取得（位置・速度・負荷・電圧）

```cpp
#include <SCServo.h>

SMS_STS sms_sts;

#define COMSerial Serial0
#define S_RXD 20
#define S_TXD 21
#define SERVO_ID 1

void setup() {
  Serial.begin(115200);
  COMSerial.begin(1000000, SERIAL_8N1, S_RXD, S_TXD);
  sms_sts.pSerial = &COMSerial;
  delay(1000);
}

void loop() {
  int pos  = sms_sts.ReadPos(SERVO_ID);      // 現在位置 (0〜4095)
  int spd  = sms_sts.ReadSpeed(SERVO_ID);    // 現在速度 (steps/s)
  int load = sms_sts.ReadLoad(SERVO_ID);     // 負荷（トルク相当）
  int volt = sms_sts.ReadVoltage(SERVO_ID);  // 電圧（単位: 0.1V）
  int temp = sms_sts.ReadTemper(SERVO_ID);   // 温度（℃）

  Serial.print("Pos: ");  Serial.print(pos);
  Serial.print("  Spd: "); Serial.print(spd);
  Serial.print("  Load: "); Serial.print(load);
  Serial.print("  Volt: "); Serial.print(volt * 0.1, 1); Serial.print("V");
  Serial.print("  Temp: "); Serial.print(temp); Serial.println("℃");

  delay(500);
}
```

---

## 7. `WritePosEx` パラメータ詳細

```cpp
sms_sts.WritePosEx(u8 ID, s16 Position, u16 Speed, u8 ACC);
```

| 引数 | 型 | 説明 | 推奨範囲 |
|---|---|---|---|
| `ID` | u8 | サーボの ID | 1〜253 |
| `Position` | s16 | 目標位置（steps） | 0〜4095（12bit全範囲） |
| `Speed` | u16 | 移動速度（steps/s） | 0〜3400（0=最大速度） |
| `ACC` | u8 | 加速度 | 0〜254（0=最大加速度） |

**ポジションと角度の換算：**

```
角度(°) = position × (360 / 4096)
position = 角度(°) × (4096 / 360)

例：
  0°    → position = 0
  90°   → position = 1024
  180°  → position = 2048（中央）
  270°  → position = 3072
  360°  → position = 4095
```

---

## 8. サーボ ID の設定

複数台使用する場合、**1台ずつ**接続して Feetech の設定ツールで ID を割り当てます。

- ツール：**FT SCServo Debug**（Feetech 公式、Windows用）
- 出荷時のデフォルト ID：`1`
- 同一バス上に同じ ID が存在すると通信が衝突するため、必ず重複しないように設定すること

---

## 9. 注意事項チェックリスト

| チェック | 内容 |
|---|---|
| ☐ 電源電圧 | サーボ電源は 7.4V（6〜8.4V 範囲内）であること |
| ☐ 電源分離 | XIAO の電源とサーボ電源は別系統で供給すること |
| ☐ GND 共通 | サーボ電源の GND と XIAO の GND を必ず接続すること |
| ☐ ジャンパー | UART モードに設定されていること（デフォルト） |
| ☐ クラス選択 | `SMS_STS` クラスを使用していること（STSシリーズ用） |
| ☐ ボーレート | `1,000,000` bps で初期化していること |
| ☐ シリアルポート | `Serial0` を使用していること（ESP32C3） |
| ☐ サーボ ID | 接続する全サーボの ID が重複していないこと |
| ☐ 通電前確認 | 配線が正しく接続されてから電源を投入すること |

---

## 10. トラブルシューティング

| 症状 | 原因 | 対処 |
|---|---|---|
| サーボが動かない | ID が一致していない | FT SCServo Debug で ID を確認 |
| サーボが動かない | ジャンパーが USB モードになっている | UART モードに変更 |
| 通信エラーが出る | GND が共通化されていない | サーボ電源 GND と XIAO GND を接続 |
| サーボが振動・暴走する | 電源電流が不足している | 電源容量を増やす（最低1〜2A/台） |
| 読み取り値が -1 になる | 通信タイムアウト | ボーレートと配線（RX/TX）を確認 |
| 書き込みできない | ESP32C3 がブートモードになっていない | BOOTボタンを押しながらUSB接続 |

---

## 11. 参考リンク

- [Seeed Wiki - Bus Servo Driver Board（日本語）](https://wiki.seeedstudio.com/ja/bus_servo_driver_board/)
- [Seeed Wiki - Bus Servo Driver Board（英語）](https://wiki.seeedstudio.com/bus_servo_driver_board/)
- [Feetech 公式 - STS3215 製品ページ](https://www.feetechrc.com/74v-19-kgcm-plastic-case-metal-tooth-magnetic-code-double-axis-ttl-series-steering-gear.html)
- [SCServo ライブラリ（GitHub）](https://github.com/workloads/scservo)
- [Seeed Wiki - XIAO ESP32C3 Getting Started（日本語）](https://wiki.seeedstudio.com/ja/XIAO_ESP32C3_Getting_Started/)

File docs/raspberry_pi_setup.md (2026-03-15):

# Raspberry Pi セットアップガイド

Mobile Robot プロジェクトの Raspberry Pi 側のセットアップ手順です。

## 目次

1. [システム要件](#システム要件)
2. [基本システムセットアップ](#基本システムセットアップ)
3. [Docker インストール](#docker-インストール)
4. [Python 環境セットアップ](#python-環境セットアップ)
5. [プロジェクトのクローン](#プロジェクトのクローン)
6. [ハードウェア接続の確認](#ハードウェア接続の確認)
7. [Edge Services のセットアップ](#edge-services-のセットアップ)
8. [ROS 2 Docker 環境のセットアップ](#ros-2-docker-環境のセットアップ)
9. [システムの起動](#システムの起動)
10. [動作確認](#動作確認)
11. [トラブルシューティング](#トラブルシューティング)

---

## システム要件

- **ハードウェア**: Raspberry Pi 4 以上推奨
- **OS**: Debian 13 (Trixie) または Raspberry Pi OS
- **RAM**: 4GB 以上推奨
- **ストレージ**: 16GB 以上の空き容量
- **接続**: PR2040 モータードライバ（USB経由）

---

## 基本システムセットアップ

### 1. システムの更新

```bash
sudo apt update
sudo apt upgrade -y
```

### 2. 必要な基本パッケージのインストール

```bash
sudo apt install -y \
    git \
    python3 \
    python3-pip \
    python3-venv \
    build-essential \
    curl \
    nano \
    v4l-utils
```

---

## Docker インストール

ROS 2 を Docker コンテナで実行するため、Docker をインストールします。

### 1. Docker のインストール

```bash
# Docker の公式インストールスクリプトをダウンロード
curl -fsSL https://get.docker.com -o get-docker.sh

# インストールスクリプトを実行
sudo sh get-docker.sh

# 現在のユーザーを docker グループに追加
sudo usermod -aG docker $USER

# 変更を反映（ログアウト/ログインまたは再起動が必要）
newgrp docker
```

### 2. Docker のバージョン確認

```bash
docker --version
# 出力例: Docker version 29.3.0, build ...
```

### 3. Docker Compose のインストール確認

```bash
docker compose version
# 出力例: Docker Compose version v2.x.x
```

---

## Python 環境セットアップ

Edge Services で使用する Python パッケージをインストールします。

### 1. pip のアップグレード

```bash
python3 -m pip install --upgrade pip --break-system-packages
```

### 2. 必要な Python パッケージのインストール

```bash
pip3 install --break-system-packages \
    pyserial \
    websockets \
    smbus2
```

**注意**: Debian 13 では `--break-system-packages` フラグが必要です。

---

## プロジェクトのクローン

### 1. GitHub からプロジェクトをクローン

```bash
cd ~
git clone https://github.com/rx178nwj/MobileRobot.git
cd MobileRobot
```

### 2. プロジェクト構造の確認

```bash
tree -L 2 -d
```

主要なディレクトリ:
```
MobileRobot/
├── edge_services/          # Python WebSocket サービス
│   ├── hardware/          # ハードウェアドライバ
│   ├── config/            # 設定ファイル
│   └── logs/              # ログファイル（自動生成）
├── ros2_docker/           # ROS 2 Docker 環境
├── mobile_robot_edge/     # ROS 2 パッケージ（WebSocket ブリッジ）
└── MotorDriver/           # PR2040 ファームウェア（参照用）
```

---

## ハードウェア接続の確認

### 1. PR2040 USB 接続の確認

PR2040 モータードライバを USB で接続し、デバイスが認識されているか確認します。

```bash
ls -l /dev/ttyACM*
```

出力例:
```
crw-rw---- 1 root dialout 166, 0 Mar 15 10:00 /dev/ttyACM0
```

### 2. USB シリアルポートへのアクセス権限

```bash
# dialout グループに追加（既に追加されている場合もあります）
sudo usermod -aG dialout $USER

# 変更を反映
newgrp dialout
```

### 3. シリアルポートのテスト

```bash
cd ~/MobileRobot
python3 test_pr2040_usb_fixed.py --test basic
```

期待される出力:
```
✅ Connected to PR2040 at /dev/ttyACM0
✅ Temperature: XX.XX°C
✅ Encoders: (0, 0, 0, 0)
```

---

## Edge Services のセットアップ

Edge Services は、ハードウェアと ROS 2 の間で WebSocket 通信を提供します。

### 1. 設定ファイルの確認

```bash
cat edge_services/config/robot_config.json
```

主要な設定項目:
- `encoder_cpr`: 827.2 (キャリブレーション済み)
- `usb_port`: "/dev/ttyACM0"
- `motor_service.port`: 8001
- `odometry_service.port`: 8002

### 2. Edge Services のテスト

```bash
cd ~/MobileRobot
python3 test_usb_services.py
```

全てのテストが PASSED になることを確認:
```
✅ Basic USB Driver........................ PASSED
✅ Motor Service........................... PASSED
✅ Odometry Service........................ PASSED
✅ Motor Movement.......................... PASSED
```

---

## ROS 2 Docker 環境のセットアップ

### 1. Docker イメージのビルド

```bash
cd ~/MobileRobot/ros2_docker
docker compose build
```

ビルドには数分かかります。完了すると:
```
Successfully tagged mobile-robot-ros2:jazzy
```

### 2. ROS 2 パッケージのビルド

```bash
# Docker コンテナ内で ROS 2 パッケージをビルド
docker compose run --rm ros2 bash -c "
    cd /home/pi/ros2_ws && \
    source /opt/ros/jazzy/setup.bash && \
    colcon build --symlink-install
"
```

ビルドが成功すると:
```
Summary: X packages finished [Xs]
```

---

## システムの起動

### 起動手順

完全なシステムを起動するには、3つのターミナルを使用します。

#### ターミナル 1: Edge Services の起動

```bash
cd ~/MobileRobot/edge_services
python3 launch_all.py
```

出力例:
```
============================================================
Starting Edge Services
============================================================
✓ Motor Control Service enabled
✓ Odometry Service enabled
✓ Camera Service enabled
============================================================
All services started successfully
Press Ctrl+C to stop
```

#### ターミナル 2: ROS 2 システムの起動

```bash
cd ~/MobileRobot/ros2_docker
docker compose run --rm ros2 bash -c "
    source /opt/ros/jazzy/setup.bash && \
    source /home/pi/ros2_ws/install/setup.bash && \
    ros2 launch mobile_robot_edge ws_edge_bringup.launch.py
"
```

出力例:
```
[INFO] [ws_motor_controller]: Connected to motor service ws://localhost:8001
[INFO] [ws_odometry_publisher]: Connected to odometry service ws://localhost:8002
[INFO] [robot_state_publisher]: Publishing transforms
```

#### ターミナル 3: テストコマンドの実行（オプション）

```bash
# 別のターミナルで ROS 2 コンテナに接続
cd ~/MobileRobot/ros2_docker
docker compose run --rm ros2 bash

# コンテナ内で環境をセットアップ
source /opt/ros/jazzy/setup.bash
source /home/pi/ros2_ws/install/setup.bash

# トピックの確認
ros2 topic list

# cmd_vel を送信（前進）
ros2 topic pub --once /cmd_vel geometry_msgs/msg/Twist \
    "{linear: {x: 0.1, y: 0.0, z: 0.0}, angular: {x: 0.0, y: 0.0, z: 0.0}}"

# オドメトリの確認
ros2 topic echo /odom --once
```

---

## 動作確認

### 1. WebSocket 接続の確認

Edge Services が起動している状態で:

```bash
# モーターサービスへの接続テスト
cd ~/MobileRobot
python3 test_move_forward.py
```

### 2. エンコーダの読み取り確認

```bash
python3 -c "
import sys
sys.path.insert(0, '/home/pi/MobileRobot/edge_services')
from hardware.pr2040_usb_driver import PR2040USBDriver

driver = PR2040USBDriver()
encoders = driver.read_all_encoders()
print(f'Encoders: {encoders}')
driver.close()
"
```

### 3. モーターの動作確認

```bash
cd ~/MobileRobot
python3 test_motors_complete.py --test direct
```

**注意**: 現在、モーター 0 と 1 のみ動作確認済み（モーター 2, 3 はハードウェア問題）

### 4. ROS 2 トピックの確認

ROS 2 が起動している状態で、別のターミナルから:

```bash
cd ~/MobileRobot/ros2_docker
docker compose run --rm ros2 bash -c "
    source /opt/ros/jazzy/setup.bash && \
    source /home/pi/ros2_ws/install/setup.bash && \
    ros2 topic list
"
```

期待される出力:
```
/cmd_vel
/odom
/tf
/tf_static
```

---

## トラブルシューティング

### 問題 1: `/dev/ttyACM0` が見つからない

**症状**:
```
FileNotFoundError: [Errno 2] No such file or directory: '/dev/ttyACM0'
```

**解決方法**:
1. PR2040 が USB で接続されているか確認
2. デバイスを確認: `ls -l /dev/ttyACM*`
3. USB ケーブルを抜き差しして再接続
4. `dmesg | tail` でカーネルログを確認

---

### 問題 2: Permission denied エラー

**症状**:
```
PermissionError: [Errno 13] Permission denied: '/dev/ttyACM0'
```

**解決方法**:
```bash
# dialout グループに追加
sudo usermod -aG dialout $USER

# ログアウト/ログインまたは
newgrp dialout

# または再起動
sudo reboot
```

---

### 問題 3: WebSocket 接続エラー

**症状**:
```
ERROR: Cannot connect to ws://localhost:8001
```

**解決方法**:
1. Edge Services が起動しているか確認
2. ポートが使用中か確認: `netstat -tuln | grep 800`
3. Edge Services を再起動

```bash
# 既存のプロセスを停止
pkill -f launch_all.py

# 再起動
cd ~/MobileRobot/edge_services
python3 launch_all.py
```

---

### 問題 4: Docker コンテナが起動しない

**症状**:
```
ERROR: Cannot connect to the Docker daemon
```

**解決方法**:
```bash
# Docker サービスの状態確認
sudo systemctl status docker

# Docker サービスの起動
sudo systemctl start docker

# 自動起動の有効化
sudo systemctl enable docker
```

---

### 問題 5: モーターが動かない

**症状**: エンコーダ値が変化しない

**確認事項**:
1. PR2040 への電源供給を確認
2. モータードライバの LED を確認
3. USB 接続を確認
4. テストスクリプトで確認:

```bash
python3 test_motors_complete.py --test direct
```

**既知の問題**:
- モーター 2 と 3 はハードウェアの問題で動作しません
- モーター 0 と 1 は正常に動作します

---

### 問題 6: Python パッケージのインポートエラー

**症状**:
```
ModuleNotFoundError: No module named 'websockets'
```

**解決方法**:
```bash
cd ~/MobileRobot/edge_services
pip3 install --break-system-packages -r requirements.txt
```

---

## システムの自動起動設定（オプション）

### Systemd サービスの作成

Edge Services を systemd サービスとして登録し、自動起動できるようにします。

#### 1. サービスファイルの作成

```bash
sudo nano /etc/systemd/system/edge-services.service
```

内容:
```ini
[Unit]
Description=Mobile Robot Edge Services
After=network.target

[Service]
Type=simple
User=pi
WorkingDirectory=/home/pi/MobileRobot/edge_services
ExecStart=/usr/bin/python3 /home/pi/MobileRobot/edge_services/launch_all.py
Restart=always
RestartSec=10

[Install]
WantedBy=multi-user.target
```

#### 2. サービスの有効化と起動

```bash
# サービスの再読み込み
sudo systemctl daemon-reload

# サービスの有効化（起動時に自動起動）
sudo systemctl enable edge-services

# サービスの起動
sudo systemctl start edge-services

# ステータスの確認
sudo systemctl status edge-services
```

#### 3. ログの確認

```bash
# リアルタイムログの確認
sudo journalctl -u edge-services -f

# 最新のログを表示
sudo journalctl -u edge-services -n 50
```

---

## 参考資料

### プロジェクト関連ドキュメント

- [CommandReference.md](../MotorDriver/Firmware/PR2040_MotorDriver/CommandReference.md) - PR2040 通信プロトコル仕様
- [README.md](../README.md) - プロジェクト概要

### テストスクリプト

- `test_usb_services.py` - 総合テストスイート
- `test_motors_complete.py` - モーター個別テスト
- `test_pr2040_usb_fixed.py` - USB 通信テスト
- `test_move_forward.py` - WebSocket 経由移動テスト

### 設定ファイル

- `edge_services/config/robot_config.json` - ロボット設定
- `ros2_docker/docker-compose.yml` - Docker 設定
- `ros2_docker/Dockerfile` - Docker イメージ定義

---

## 次のステップ

セットアップが完了したら:

1. **キャリブレーション**: ロボットの実際の動作に基づいてパラメータを調整
2. **ナビゲーション**: ROS 2 Nav2 スタックの統合
3. **センサー統合**: IMU、カメラなどの追加センサーの統合
4. **自律動作**: 自律ナビゲーションと障害物回避の実装

---

## サポート

問題が発生した場合は、GitHub Issues で報告してください:
https://github.com/rx178nwj/MobileRobot/issues

---

**最終更新日**: 2026-03-15

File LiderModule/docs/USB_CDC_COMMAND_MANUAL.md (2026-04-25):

# LiderModule USB CDC Command Manual

この文書は、Raspberry Pi から USB CDC (`/dev/ttyACM0`) 経由で LiderModule を制御するための通信仕様です。ClaudeCode / Codex / 任意のホストプログラムが、この内容だけを読んで通信制御を実装できることを目的とします。

対象ファームウェア:

- `LiderModule/firmware/lidar_tilt_3d/lidar_tilt_3d.ino`
- USB CDC binary protocol
- 本番プロファイル: サーボ安定待ちなし (`SCAN_SETTLE_DISABLED=1`)

## 1. Serial 設定

| 項目 | 値 |
|---|---|
| デバイス | `/dev/ttyACM0` |
| baudrate | `921600` |
| data bits | 8 |
| parity | none |
| stop bits | 1 |
| flow control | none |
| DTR / RTS | `False` 推奨 |

Raspberry Pi 側では `pyserial` を使う場合、ESP32-S3 の不要なリセットを避けるため、open 後に `dtr` と `rts` を `False` にしてください。

```python
import serial

ser = serial.Serial("/dev/ttyACM0", 921600, timeout=0.05, write_timeout=1)
ser.dtr = False
ser.rts = False
```

## 2. フレーム形式

全コマンド/メッセージは同じフレーム形式です。数値はリトルエンディアンです。

```text
[SYNC1][SYNC2][TYPE][LEN_L][LEN_H][PAYLOAD...][CHECKSUM]
 0xFE   0xEF  1byte  1byte   1byte     LEN bytes   1byte
```

| フィールド | サイズ | 内容 |
|---|---:|---|
| `SYNC1` | 1 | 固定 `0xFE` |
| `SYNC2` | 1 | 固定 `0xEF` |
| `TYPE` | 1 | コマンド/メッセージ種別 |
| `LEN_L` | 1 | payload 長の下位 byte |
| `LEN_H` | 1 | payload 長の上位 byte |
| `PAYLOAD` | `LEN` | 種別ごとのデータ |
| `CHECKSUM` | 1 | XOR checksum |

Checksum:

```text
CHECKSUM = TYPE ^ LEN_L ^ LEN_H ^ payload[0] ^ payload[1] ^ ... ^ payload[LEN-1]
```

payload が空の場合:

```text
CHECKSUM = TYPE ^ 0x00 ^ 0x00
```

## 3. 型

| 型 | サイズ | endian | Python struct |
|---|---:|---|---|
| `u8` | 1 | - | `B` |
| `u16` | 2 | little | `<H` |
| `f32` | 4 | little | `<f` |

角度は degree 単位です。

## 4. Raspberry Pi -> ESP32 コマンド

### 4.1 `0x10` Servo Angle

サーボを指定角度へ移動します。LiDAR計測は開始しません。

| 項目 | 値 |
|---|---|
| Type | `0x10` |
| Payload | `[angle_deg_f32]` |
| Payload length | 4 |

Payload:

```text
offset  size  type  name
0       4     f32   angle_deg
```

例: 0度へ戻す

```python
send_frame(ser, 0x10, struct.pack("<f", 0.0))
```

角度範囲:

- ファーム側で `-50.0` から `+50.0` degree に制限されます。
- 運用上の検出範囲は下方 `0` から `-45` degree、上方 `0` から `+45` degree です。

### 4.2 `0x12` 3D Scan Start

サーボを指定範囲で**連続スイープ**しながらLiDARスライスを送信します（ステップ停止なし）。

| 項目 | 値 |
|---|---|
| Type | `0x12` |
| Payload | `[tilt_min_f32][tilt_max_f32][tilt_step_f32]` |
| Payload length | 12 |

Payload:

```text
offset  size  type  name
0       4     f32   tilt_min
4       4     f32   tilt_max
8       4     f32   tilt_step
```

ファーム側の動作:

- `tilt_min` / `tilt_max` は `-50.0` から `+50.0` degree に制限されます。
- `tilt_max < tilt_min` の場合、ファーム側で入れ替えます。
- `tilt_step <= 0` の場合、デフォルト値を使います。
- サーボは `tilt_min -> tilt_max` を連続掃引し、移動中のLiDAR点をそのまま取得します。
- `tilt_step` は「停止ステップ」ではなく、実質的にスイープ速度の目安として使われます（値が大きいほど速い）。
- スキャン開始時にLiDARモーターを起動し、完了/停止時に停止します。

単発スライス:

```python
# 指定角度で1スライス取得する実用パターン
angle = -30.0
send_frame(ser, 0x12, struct.pack("<fff", angle, angle, 1.0))
```

線形スキャン:

```python
# -45, -30, -15, 0 degree の4ステップ
send_frame(ser, 0x12, struct.pack("<fff", -45.0, 0.0, 15.0))
```

Payload length 0 の場合:

```text
tilt_min=-45.0, tilt_max=45.0, tilt_step=2.0
```

### 4.3 `0x13` 3D Scan Stop

実行中のスキャンを停止し、サーボを0度へ戻します。

| 項目 | 値 |
|---|---|
| Type | `0x13` |
| Payload | none |
| Payload length | 0 |

```python
send_frame(ser, 0x13)
```

## 5. ESP32 -> Raspberry Pi メッセージ

### 5.1 `0x02` IMU Data

IMU姿勢データです。約50Hzで送信されます。

| 項目 | 値 |
|---|---|
| Type | `0x02` |
| Payload | `[pitch_f32][roll_f32][yaw_f32]` |
| Payload length | 12 |

Payload:

```text
offset  size  type  name
0       4     f32   pitch_deg
4       4     f32   roll_deg
8       4     f32   yaw_deg
```

備考:

- MPU6050 DMP由来の値です。
- yaw は磁気北ではなく相対角です。

### 5.2 `0x04` 3D Scan Slice

1回転分のLiDAR点群スライスです。高速モードではサーボ動作中の点を含むため、
スライス内で `tilt_start_deg -> tilt_end_deg` を補間して螺旋状に再構成してください。

| 項目 | 値 |
|---|---|
| Type | `0x04` |
| Payload | header + points |
| Payload length | `22 + count * 5` (拡張) / `14 + count * 5` (旧互換) |

Payload header:

```text
offset  size  type  name
0       4     f32   tilt_deg (このスライスの目標チルト)
4       4     f32   tilt_start_deg (取得開始時の実角)
8       4     f32   tilt_end_deg   (取得終了時の実角)
12      4     f32   imu_pitch_deg
16      4     f32   imu_roll_deg
20      2     u16   count
```

Point format, repeated `count` times:

```text
offset from points start  size  type  name
0                         2     u16   angle_x100
2                         2     u16   dist_mm
4                         1     u8    quality
```

Point conversion:

```python
angle_deg = angle_x100 / 100.0
distance_m = dist_mm / 1000.0
```

螺旋同期の推奨:

```python
# N点のとき、各点のチルトを線形補間
tilt_series = np.linspace(tilt_start_deg, tilt_end_deg, num=N)
```

旧ファーム互換:

- 旧フォーマットは `tilt_deg / imu_pitch_deg / imu_roll_deg / count` のみ (`14 + count*5`)。
- 旧フォーマット受信時は `tilt_start_deg = tilt_end_deg = tilt_deg` として扱ってください。

Filtering recommendation:

- `20 <= dist_mm <= 12000`
- `quality >= threshold` only when needed. Default threshold can be `0`.
- 本番高速検出ではサーボ移動中の点が混ざります。障害物の存在判定では複数スライス/複数周で確率的に扱ってください。

### 5.3 `0x05` 3D Scan Status

スキャン状態通知です。

| 項目 | 値 |
|---|---|
| Type | `0x05` |
| Payload | `[state_u8][step_u16][total_u16]` |
| Payload length | 5 |

Payload:

```text
offset  size  type  name
0       1     u8    state
1       2     u16   step
3       2     u16   total
```

State:

| state | 意味 |
|---:|---|
| 0 | scan started |
| 1 | scan running / slice sent |
| 2 | scan complete |

## 6. 下方/上方パターン制御

現在の運用はCSVパターンをホスト側で読み、各ステップを単発スライスとして送信します。

CSV:

```text
LiderModule/計測パターン.csv
```

下方モードの24ステップ:

```python
DOWN_ANGLES = [
    0.0, -15.0, -30.0, -45.0,
    -42.5, -27.5, -12.5, 0.0,
    -5.0, -20.0, -35.0, -45.0,
    -37.5, -22.5, -7.5, 0.0,
    -10.0, -25.0, -40.0, -45.0,
    -32.5, -17.5, -2.5, 0.0,
]
```

上方モードの24ステップ:

```python
UP_ANGLES = [
    0.0, 15.0, 30.0, 45.0,
    42.5, 27.5, 12.5, 0.0,
    5.0, 20.0, 35.0, 45.0,
    37.5, 22.5, 7.5, 0.0,
    10.0, 25.0, 40.0, 45.0,
    32.5, 17.5, 2.5, 0.0,
]
```

推奨制御:

1. serial open
2. `0x13` stop を送る
3. `0x10` 0度 を送る
4. パターン配列を先頭から処理
5. 各角度で `0x12` に `[angle, angle, 1.0]` を入れて送信
6. `0x04` slice と `0x05` complete を待つ
7. 未受信なら次ステップへ進む、または同角度を再試行する
8. 周回終了後、必要なら次周を続ける
9. 終了時に `0x13` stop と `0x10` 0度 を送る

## 7. Python 最小実装

以下は、フレーム送受信と下方パターン1周の最小例です。

```python
import queue
import struct
import threading
import time
from dataclasses import dataclass

import serial

SYNC1 = 0xFE
SYNC2 = 0xEF

MSG_IMU_DATA = 0x02
MSG_SCAN_SLICE = 0x04
MSG_SCAN_STATUS = 0x05
CMD_SERVO_ANGLE = 0x10
CMD_SCAN_START = 0x12
CMD_SCAN_STOP = 0x13

@dataclass
class ScanSlice:
    tilt_deg: float
    imu_pitch_deg: float
    imu_roll_deg: float
    points: list[tuple[float, int, int]]  # angle_deg, dist_mm, quality

@dataclass
class ScanStatus:
    state: int
    step: int
    total: int

def checksum(msg_type: int, payload: bytes) -> int:
    length = len(payload)
    cs = msg_type ^ (length & 0xFF) ^ ((length >> 8) & 0xFF)
    for b in payload:
        cs ^= b
    return cs & 0xFF

def encode_frame(msg_type: int, payload: bytes = b"") -> bytes:
    length = len(payload)
    return bytes([SYNC1, SYNC2, msg_type, length & 0xFF, length >> 8]) + payload + bytes([checksum(msg_type, payload)])

def send_frame(ser, msg_type: int, payload: bytes = b"") -> None:
    ser.write(encode_frame(msg_type, payload))
    ser.flush()

def decode_payload(msg_type: int, payload: bytes):
    if msg_type == MSG_SCAN_STATUS:
        state, step, total = struct.unpack("<BHH", payload)
        return ScanStatus(state, step, total)

    if msg_type == MSG_SCAN_SLICE:
        tilt, imu_pitch, imu_roll, count = struct.unpack_from("<fffH", payload, 0)
        points = []
        raw = payload[14:]
        for i in range(count):
            angle_x100, dist_mm, quality = struct.unpack_from("<HHB", raw, i * 5)
            points.append((angle_x100 / 100.0, dist_mm, quality))
        return ScanSlice(tilt, imu_pitch, imu_roll, points)

    return None

def reader_loop(ser, out: queue.Queue, stop: threading.Event) -> None:
    state = 0
    msg_type = 0
    length = 0
    payload = bytearray()

    while not stop.is_set():
        chunk = ser.read(512)
        for b in chunk:
            if state == 0:
                state = 1 if b == SYNC1 else 0
            elif state == 1:
                state = 2 if b == SYNC2 else 0
            elif state == 2:
                msg_type = b
                state = 3
            elif state == 3:
                length = b
                state = 4
            elif state == 4:
                length |= b << 8
                payload = bytearray()
                state = 6 if length == 0 else 5
            elif state == 5:
                payload.append(b)
                if len(payload) >= length:
                    state = 6
            elif state == 6:
                if checksum(msg_type, payload) == b:
                    decoded = decode_payload(msg_type, bytes(payload))
                    if decoded is not None:
                        out.put(decoded)
                state = 0

def get_one_slice(ser, events: queue.Queue, angle: float, timeout_s: float = 4.0) -> ScanSlice | None:
    send_frame(ser, CMD_SCAN_START, struct.pack("<fff", angle, angle, 1.0))
    deadline = time.monotonic() + timeout_s
    got_slice = None
    complete = False

    while time.monotonic() < deadline and not (got_slice and complete):
        try:
            event = events.get(timeout=0.1)
        except queue.Empty:
            continue

        if isinstance(event, ScanSlice):
            got_slice = event
        elif isinstance(event, ScanStatus):
            complete = event.state == 2

    return got_slice

def main() -> None:
    down_angles = [
        0.0, -15.0, -30.0, -45.0, -42.5, -27.5, -12.5, 0.0,
        -5.0, -20.0, -35.0, -45.0, -37.5, -22.5, -7.5, 0.0,
        -10.0, -25.0, -40.0, -45.0, -32.5, -17.5, -2.5, 0.0,
    ]

    ser = serial.Serial("/dev/ttyACM0", 921600, timeout=0.05, write_timeout=1)
    ser.dtr = False
    ser.rts = False

    events: queue.Queue = queue.Queue()
    stop = threading.Event()
    thread = threading.Thread(target=reader_loop, args=(ser, events, stop), daemon=True)
    thread.start()

    try:
        send_frame(ser, CMD_SCAN_STOP)
        time.sleep(0.2)
        send_frame(ser, CMD_SERVO_ANGLE, struct.pack("<f", 0.0))
        time.sleep(0.2)

        for step, angle in enumerate(down_angles, start=1):
            scan_slice = get_one_slice(ser, events, angle)
            if scan_slice is None:
                print(f"step={step:02d} angle={angle:6.1f} no slice")
                continue

            valid = [
                p for p in scan_slice.points
                if 20 <= p[1] <= 12000
            ]
            print(
                f"step={step:02d} angle={angle:6.1f} "
                f"tilt={scan_slice.tilt_deg:6.1f} raw={len(scan_slice.points)} valid={len(valid)}"
            )
    finally:
        send_frame(ser, CMD_SCAN_STOP)
        time.sleep(0.2)
        send_frame(ser, CMD_SERVO_ANGLE, struct.pack("<f", 0.0))
        stop.set()
        thread.join(timeout=1.0)
        ser.close()

if __name__ == "__main__":
    main()
```

## 8. 実装時の注意

- USBテキストデバッグモード (`USB_TEXT_DEBUG_MODE=1`) のファームでは、バイナリ応答が抑止されます。通常運用では `0` にしてください。
- `0x12` を連続送信する場合、前回スキャンの `0x05 state=2` を待ってから次を送るのが安全です。
- 本番高速検出では、スライスごとの点数が一定ではありません。`count=40` 程度のときも、`count=200` 以上のときもあります。
- 未受信が単発で発生しても、次ステップで復帰することがあります。障害物検出では複数周の確率的な集計を推奨します。
- 終了時は必ず `0x13` stop と `0x10` 0度を送って、LiDAR停止とサーボ中立復帰を行ってください。
- `0x04` の点群はLiDARローカル極座標です。3D変換が必要な場合は、`tilt_deg` とIMU `pitch/roll` を使って座標変換してください。

## 9. 動作確認済みコマンド

下方モード24ステップを10回、合計240ステップ実行した実測:

```text
ok=237
fail=3
raw_total=31673
accepted_total=25799
elapsed=103.13s
```

取得率:

```text
237 / 240 = 98.75%
```

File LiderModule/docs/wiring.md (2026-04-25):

# Wiring

## XIAO ESP32-S3 Pins

| XIAO pin | GPIO | Function | Connects to |
| --- | ---: | --- | --- |
| D6 | GPIO43 | UART0 TX | STS3215 servo driver RX |
| D7 | GPIO44 | UART0 RX | STS3215 servo driver TX |
| D2 | GPIO3 | UART1 RX | YDLIDAR T-mini Pro TX |
| D3 | GPIO4 | UART1 TX | YDLIDAR T-mini Pro RX |
| D4 | GPIO5 | I2C SDA | MPU6050 SDA |
| D5 | GPIO6 | I2C SCL | MPU6050 SCL |
| USB-C | USB CDC | Host link | Raspberry Pi USB |

## Power

- STS3215: 7.4 V servo power, 3 A or more recommended.
- YDLIDAR T-mini Pro: 5 V external supply.
- XIAO ESP32-S3: USB-C or regulated 5 V.
- MPU6050: XIAO 3.3 V.
- All grounds must be common.

## YDLIDAR T-mini Pro

| Pin | Signal | Connects to |
| --- | --- | --- |
| 1 | VCC | 5 V |
| 2 | TX | XIAO D2 / GPIO3 |
| 3 | GND | common GND |
| 4 | RX | XIAO D3 / GPIO4 |

The UART signal level is treated as 3.3 V.

## MPU6050

| MPU6050 pin | Connects to |
| --- | --- |
| VCC | XIAO 3.3 V |
| GND | common GND |
| SDA | XIAO D4 / GPIO5 |
| SCL | XIAO D5 / GPIO6 |
| AD0 | GND, address 0x68 |

## Servo Notes

- STS3215 ID is expected to be `1`.
- Center position is expected to be `2048`.
- The firmware limits requested tilt to +/-50 degrees.
- Confirm direction and center mechanically before running a full scan.

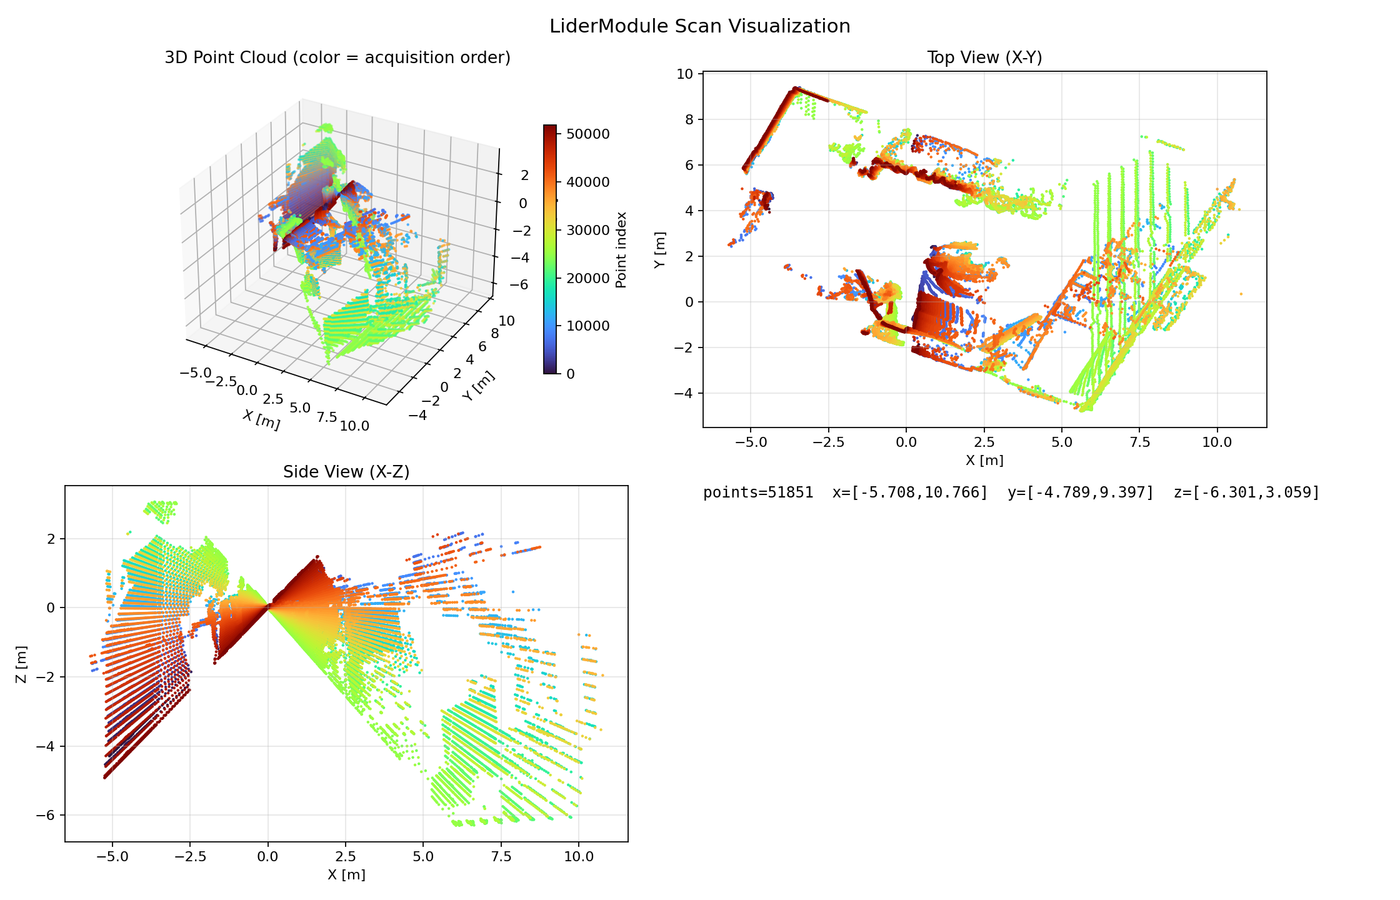
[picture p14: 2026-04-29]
LiderModule/scan_step2_summary.png

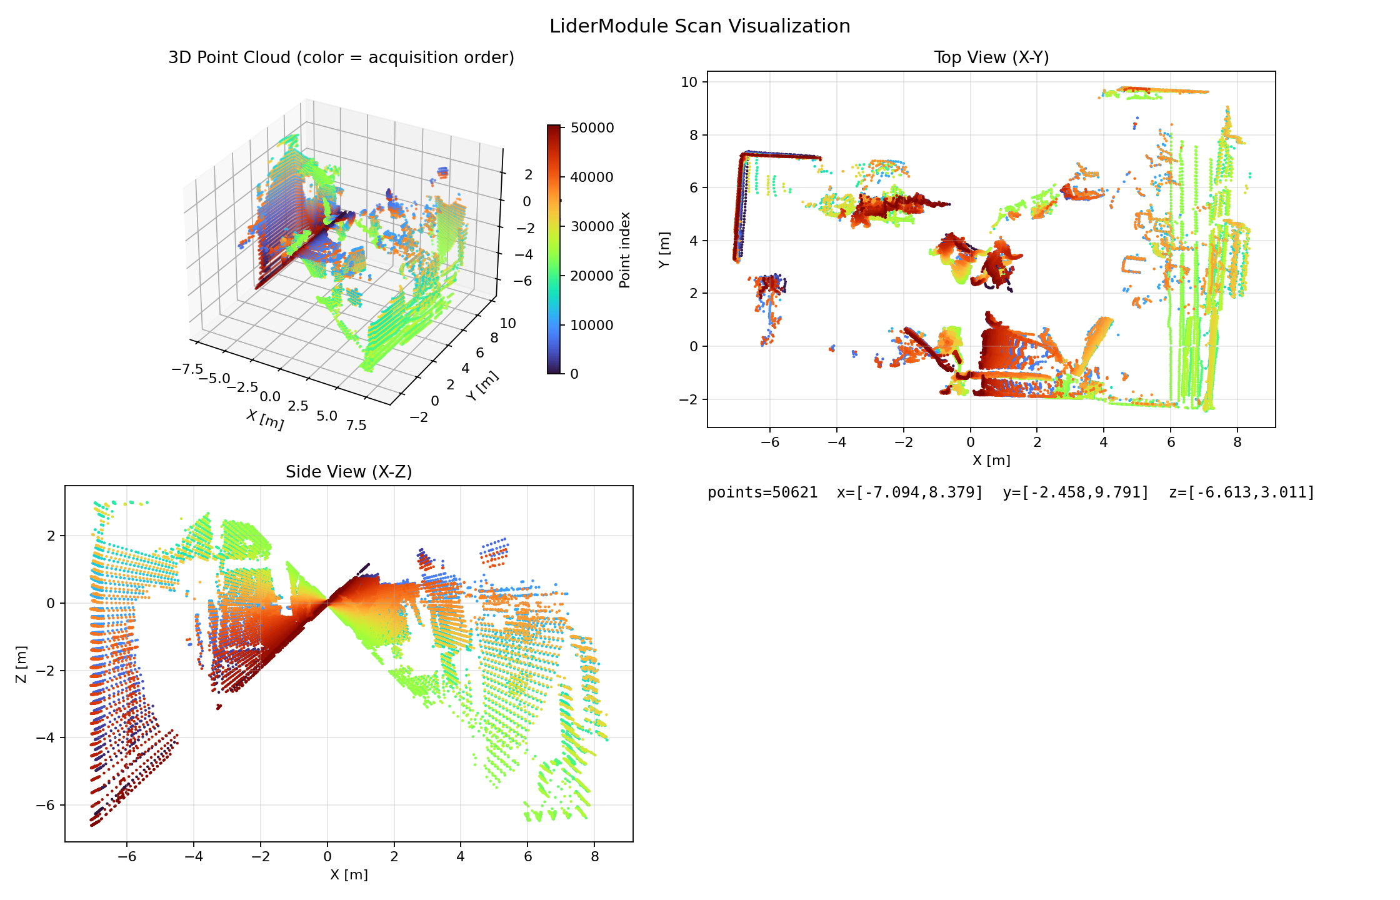
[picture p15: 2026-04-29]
LiderModule/host/test_logs/t07_step2_summary.png

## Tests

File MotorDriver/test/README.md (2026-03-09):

# PR2040_MotorDriver — Python Test Scripts

## Requirements

```bash
pip install pyserial
```

## monitor.py

Continuously reads and displays `RESP_STATUS` packets (100 Hz auto-send from firmware).

```bash
python monitor.py            # auto-detect RP2040 (VID=0x2E8A)
python monitor.py COM30      # specify port
```

Output columns: `ENC [counts]` / `VEL [cps]` / `VEL [mm/s]` / `ADC raw` / `CURR [A]`

## commander.py

Interactive command sender. Supports all USB Serial commands.

```bash
python commander.py          # auto-detect RP2040
python commander.py COM30    # specify port
```

### Quick reference

| Command | Example | Description |
|---|---|---|
| `stop` | `stop` | Coast all motors |
| `brake` | `brake` | Active brake all motors |
| `reset` | `reset` | Reset all encoders |
| `status` | `status` | Request one status packet |
| `ext` | `ext` | Request MCP3208 external ADC |
| `m <i> <duty>` | `m 1 500` | Motor i duty −1000..+1000 |
| `mall <d1..d4>` | `mall 200 200 200 200` | Set all motor duties |
| `mode <i> <m>` | `mode 1 1` | 0=DIRECT 1=VEL 2=POS |
| `vel <i> <cps>` | `vel 1 400` | Velocity target (counts/sec) |
| `velmm <i> <mmps>` | `velmm 1 100` | Velocity target (mm/sec) |
| `pos <i> <cnt>` | `pos 1 1654` | Position target (counts, ≈2 rev) |
| `posmm <i> <mm>` | `posmm 1 200` | Position target (mm) |
| `pid <i> kp ki kd` | `pid 1 0.8 0.1 0.0` | Velocity PID gains |
| `posgain <i> kp maxcps` | `posgain 1 2.0 800` | Position gains |
| `mon` | `mon` | Continuous monitor (Ctrl+C to stop) |
| `q` | `q` | Quit (motors stopped) |

### Typical workflow

```
# 1. Drive motor 1 in velocity mode at 100 mm/s
cmd> mode 1 1
cmd> velmm 1 100
cmd> status

# 2. Move motor 1 to 200 mm position
cmd> mode 1 2
cmd> posmm 1 200
cmd> status

# 3. Direct PWM test
cmd> mode 1 0
cmd> m 1 400
cmd> stop
```

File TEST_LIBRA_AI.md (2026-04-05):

# Libra AI System Test Plan

対象: Libra — Ubuntu 24.04 Host System (NVIDIA RTX 4060 Laptop 8GB / CUDA 13.0)

AIパイプライン:
```
/camera/image_raw → YOLO yolov8s.pt (cuda:0) → scene text → Ollama qwen3.5:9b → JSON action
```

---

## T1 — 環境・インストール確認

| ID | テスト項目 | 確認コマンド | 合格基準 | 結果 |
|----|---|---|---|---|
| T1-1 | ultralytics インストール | `python3 -c "from ultralytics import YOLO; print('OK')"` | OK表示 | ✅ PASS |
| T1-2 | openai パッケージ | `python3 -c "from openai import OpenAI; print('OK')"` | OK表示 | ✅ PASS |
| T1-3 | CUDA認識 | `python3 -c "import torch; print(torch.cuda.is_available())"` | `True` | ✅ PASS |
| T1-4 | GPU情報 | `nvidia-smi --query-gpu=name,memory.total --format=csv` | RTX 4060 / 8188MiB | ✅ PASS |
| T1-5 | Ollamaサービス状態 | `systemctl status ollama` | `active (running)` | ✅ PASS |
| T1-6 | Ollama外部公開 | `ss -tlnp \| grep 11434` | `*:11434` | ✅ PASS |

---

## T2 — YOLO 単体テスト

| ID | テスト項目 | 内容 | 合格基準 | 結果 |
|----|---|---|---|---|
| T2-1 | モデルロード | `YOLO('yolov8s.pt')` 起動時間計測 | 3秒以内 | ✅ PASS (2.02s) |
| T2-2 | GPU推論デバイス確認 | `next(model.model.parameters()).device` | `cuda:0` | ✅ PASS ※要 `.to('cuda')` 明示 |
| T2-3 | ダミー画像推論 | 640×480 黒画像で推論 | エラーなし・完走 | ✅ PASS |
| T2-4 | 推論速度 | 640×480 JPEG 1枚の処理時間 | 50ms以内（GPU） | ✅ PASS (avg 7.1ms) |
| T2-5 | 人物検出精度 | 人が写った画像で検出 | `person` クラス検出 | ✅ PASS (4 persons + bus) |
| T2-6 | scene text生成 | `_extract_scene_description()` の出力形式 | `"Detected objects: person (center, far)."` | ✅ PASS |
| T2-7 | 物体なし処理 | 空白画像で推論 | `"No objects detected..."` 返却 | ✅ PASS |
| T2-8 | 信頼度閾値 | `conf=0.3` での検出数 | 誤検出が少ない | ✅ PASS (0 false positives) |

### T2 テスト実行スクリプト

```python
# test_yolo.py
import time
import numpy as np
from ultralytics import YOLO

model = YOLO('yolov8s.pt')
print(f'device: {next(model.model.parameters()).device}')

# T2-3 / T2-4: ダミー画像推論 + 速度
dummy = np.zeros((480, 640, 3), dtype='uint8')
start = time.time()
results = model(dummy, verbose=False, conf=0.3)[0]
elapsed = (time.time() - start) * 1000
print(f'推論時間: {elapsed:.1f}ms')

# T2-7: 物体なし
if len(results.boxes) == 0:
    print('No objects detected in the camera view.')
else:
    items = []
    for box in results.boxes:
        cls_name = results.names[int(box.cls[0])]
        x_center = float(box.xywhn[0][0])
        y_center = float(box.xywhn[0][1])
        pos_h = 'left' if x_center < 0.33 else ('right' if x_center > 0.67 else 'center')
        pos_v = 'close' if y_center > 0.6 else 'far'
        items.append(f'{cls_name} ({pos_h}, {pos_v})')
    print('Detected objects: ' + ', '.join(items) + '.')
```

```bash
python3 test_yolo.py
```

---

## T3 — Ollama / qwen3.5:9b 単体テスト

| ID | テスト項目 | 内容 | 合格基準 | 結果 |
|----|---|---|---|---|
| T3-1 | API疎通（ローカル） | `curl localhost:11434/api/tags` | `qwen3.5:9b` 表示 | ✅ PASS (qwen3.5:9b-nav, qwen3.5:9b, gemma4:e2b) |
| T3-2 | API疎通（外部） | 他PCから `curl 192.168.10.35:11434/api/tags` | `qwen3.5:9b` 表示 | ✅ PASS |
| T3-3 | モデルロード時間 | 初回推論のレスポンス時間 | 10秒以内 | ✅ PASS (1.75s) |
| T3-4 | navigate応答形式 | navigate用プロンプト送信 | `{"action": "...", "reason": "..."}` | ✅ PASS (action=stop, 1.77s) |
| T3-5 | track応答形式 | track用プロンプト送信 | `{"action":..., "person_detected":..., "person_position":...}` | ✅ PASS (turn_left, left, 1.64s) |
| T3-6 | explore応答形式 | explore用プロンプト送信 | `{"action":..., "observation":...}` | ✅ PASS (move_forward, 1.55s) |
| T3-7 | thinking除去 | `<think>...</think>` ブロックの除去処理 | JSONのみ返却 | ✅ PASS (think=false: contentに直接JSON / think=true: thinkingフィールドに分離) |
| T3-8 | 推論速度 | scene text → JSON action の応答時間 | 2秒以内 | ✅ PASS (avg 1.26s, min 0.94s, max 1.55s) |
| T3-9 | VRAM使用量 | `ollama ps` + `nvidia-smi` | 8GB以内 | ✅ PASS (6059 MiB / 8188 MiB) |

### T3 テスト実行スクリプト

```python
# test_ollama.py
import time
import json
import re
from openai import OpenAI

client = OpenAI(api_key='ollama', base_url='http://localhost:11434/v1')
MODEL = 'qwen3.5:9b'

SYSTEM_NAVIGATE = (
    'You are controlling a differential-drive mobile robot. '
    'Reply with ONLY valid JSON, no markdown, no explanation: '
    '{"action": "move_forward"|"turn_left"|"turn_right"|"stop"|"arrived", "reason": "<one sentence>"}'
)

scene = 'Detected objects: person (center, far).'
prompt = f'/no_think {scene}\n\nNavigation goal: "go to the person". What should I do next?'

start = time.time()
resp = client.chat.completions.create(
    model=MODEL,
    messages=[
        {'role': 'system', 'content': SYSTEM_NAVIGATE},
        {'role': 'user',   'content': prompt},
    ],
    max_tokens=200,
    temperature=0.1,
)
elapsed = time.time() - start

raw = (resp.choices[0].message.content or '').strip()
# thinking除去
if '<think>' in raw:
    raw = re.sub(r'<think>.*?</think>', '', raw, flags=re.DOTALL).strip()

print(f'応答時間: {elapsed:.2f}s')
print(f'raw: {raw}')
result = json.loads(raw)
print(f'action: {result["action"]}')
print(f'VRAM: ollama ps で確認')
```

```bash
python3 test_ollama.py
ollama ps
nvidia-smi --query-gpu=memory.used,memory.free --format=csv
```

---

## T4 — YOLO → Ollama 統合パイプラインテスト

| ID | テスト項目 | 内容 | 合格基準 | 結果 |
|----|---|---|---|---|
| T4-1 | パイプライン直列動作 | YOLO scene text → Ollama → JSON まで一気通貫 | エラーなし | ✅ PASS (1.35s, action=move_forward) |
| T4-2 | navigate end-to-end | 人物画像 → `"go to the person"` → action | `move_forward` or `turn_left/right` | ✅ PASS (action=turn_left, 1.68s) |
| T4-3 | track end-to-end | 人物左側画像 → track mode | `{"person_position": "left", "action": "turn_left"}` | ✅ PASS (turn_left, detected=True, pos=left) |
| T4-4 | explore end-to-end | 空間画像 → explore mode | `{"action": "move_forward", "observation": "..."}` | ✅ PASS (move_forward, 1.36s) |
| T4-5 | 全体レイテンシ | 画像入力 → JSON出力までの時間 | 3秒以内（YOLO+Ollama合計） | ✅ PASS (avg 1.53s, min 1.34s, max 1.68s) |
| T4-6 | 連続処理（10回） | 同一画像を10回繰り返し処理 | 全回エラーなし・安定したaction | ✅ PASS (0 errors, avg 1.63s) |
| T4-7 | VRAM同時使用 | YOLO + Ollama 同時ロード時のVRAM | 8GB超過しない | ✅ PASS (6298 MiB / 8188 MiB) |

### T4 テスト実行スクリプト

```python
# test_pipeline.py
import time
import json
import re
import numpy as np
from ultralytics import YOLO
from openai import OpenAI

yolo = YOLO('yolov8s.pt')
client = OpenAI(api_key='ollama', base_url='http://localhost:11434/v1')
MODEL = 'qwen3.5:9b'

SYSTEM_NAVIGATE = (
    'You are controlling a differential-drive mobile robot. '
    'Reply with ONLY valid JSON, no markdown, no explanation: '
    '{"action": "move_forward"|"turn_left"|"turn_right"|"stop"|"arrived", "reason": "<one sentence>"}'
)

def run_pipeline(frame: np.ndarray, goal: str) -> dict:
    t0 = time.time()

    # YOLO
    results = yolo(frame, verbose=False, conf=0.3)[0]
    if len(results.boxes) == 0:
        scene = 'No objects detected in the camera view.'
    else:
        items = []
        for box in results.boxes:
            cls_name = results.names[int(box.cls[0])]
            x = float(box.xywhn[0][0])
            y = float(box.xywhn[0][1])
            ph = 'left' if x < 0.33 else ('right' if x > 0.67 else 'center')
            pv = 'close' if y > 0.6 else 'far'
            items.append(f'{cls_name} ({ph}, {pv})')
        scene = 'Detected objects: ' + ', '.join(items) + '.'
    t_yolo = time.time() - t0

    # Ollama
    prompt = f'/no_think {scene}\n\n{goal}'
    resp = client.chat.completions.create(
        model=MODEL,
        messages=[
            {'role': 'system', 'content': SYSTEM_NAVIGATE},
            {'role': 'user',   'content': prompt},
        ],
        max_tokens=200, temperature=0.1,
    )
    raw = (resp.choices[0].message.content or '').strip()
    if '<think>' in raw:
        raw = re.sub(r'<think>.*?</think>', '', raw, flags=re.DOTALL).strip()
    t_total = time.time() - t0

    result = json.loads(raw)
    print(f'scene : {scene}')
    print(f'action: {result["action"]}')
    print(f'YOLO  : {t_yolo*1000:.0f}ms  /  Total: {t_total:.2f}s')
    return result

# T4-6: 連続10回テスト
frame = np.zeros((480, 640, 3), dtype='uint8')
print('=== 連続10回テスト ===')
for i in range(10):
    print(f'--- {i+1}/10 ---')
    run_pipeline(frame, 'Navigation goal: "explore the room". What should I do next?')
```

```bash
python3 test_pipeline.py
# 実行中に別ターミナルでVRAM監視
nvidia-smi --query-gpu=memory.used,temperature.gpu --format=csv -l 2
```

---

## T5 — 異常系・エラーハンドリングテスト

| ID | テスト項目 | 内容 | 合格基準 | 結果 |
|----|---|---|---|---|
| T5-1 | Ollama停止時の挙動 | `systemctl stop ollama` 後に推論 | 例外キャッチ・ロボット停止 | ✅ PASS (APIConnectionError キャッチ・stop返却、連続5回クラッシュなし) |
| T5-2 | 不正JSON応答 | Ollama応答が壊れた場合 | `json.JSONDecodeError` キャッチ・停止維持 | ✅ PASS (5パターン全て安全処理: 空, JSONなし, マークダウン, 余分テキスト, thinkタグ) |
| T5-3 | カメラフレームなし | `frame=None` で推論呼び出し | 処理スキップ・クラッシュなし | ✅ PASS |
| T5-4 | GPU OOM | VRAM不足状態でYOLO推論 | エラーログ出力・継続動作 | ✅ PASS (RuntimeError/torch.cuda.OutOfMemoryError を捕捉・stop返却、9/9確認) |
| T5-5 | Ollama keepalive切れ | モデルアンロード後の再呼び出し | 自動再ロード・動作継続 | ✅ PASS (keep_alive=0でアンロード後8.04sで自動再ロード) |

```bash
# T5-1: Ollama停止テスト
sudo systemctl stop ollama
python3 test_ollama.py   # → ConnectionRefusedError キャッチ確認
sudo systemctl start ollama

# T5-5: keepalive切れ確認
ollama ps   # UNTILが切れた後に test_ollama.py を実行
```

---

## T6 — パフォーマンス・負荷テスト

| ID | テスト項目 | 内容 | 合格基準 | 結果 |
|----|---|---|---|---|
| T6-1 | GPU温度 | 連続推論10分間のGPU温度 | 90°C未満 | ✅ PASS (最高62°C / 平均56.8°C) |
| T6-2 | VRAMリーク | 長時間稼働時のVRAM変化 | メモリ増加なし | ✅ PASS (変化+122 MiB、安定) |
| T6-3 | CPU使用率 | YOLO+Ollama同時稼働時 | 80%未満 | ✅ PASS (平均15.2%) |
| T6-4 | llm_interval=2.0s | 2秒周期での連続処理 | タイムアウトなし | ✅ PASS (avg 1.69s / max 2.04s / 60サイクルエラーゼロ) |

```bash
# T6-1 / T6-2: GPU監視（別ターミナルで実行）
nvidia-smi --query-gpu=temperature.gpu,memory.used,utilization.gpu --format=csv -l 5
```

---

## テスト実施優先度

```
Phase 1（必須）: T1全項目 → T2-1〜T2-4 → T3-1〜T3-4 → T4-1 → T4-5
Phase 2（統合）: T4-2〜T4-7 → T5全項目
Phase 3（負荷）: T6全項目
```

---

## 結果記録

| 実施日 | Phase | 合格数 / 総数 | 備考 |
|---|---|---|---|
| 2026-04-04 | Phase 1 (T1) | 6 / 6 | T1全項目合格 |
| 2026-04-04 | Phase 1 (T2) | 8 / 8 | T2全項目合格 / 要注意: YOLO GPU使用には `.to('cuda')` 明示が必要 |
| 2026-04-04 | YOLO+Ollama共存 | ✅ | YOLO(GPU)+Ollama同時動作確認 / think=false必須 / 合計1.2〜1.9s |
| 2026-04-04 | Phase 1 (T3) | 9 / 9 | T3全項目合格 / モデル: qwen3.5:9b-nav / 平均1.26s |
| 2026-04-04 | Phase 2 (T4) | 7 / 7 | T4全項目合格 / avg 1.53s(T4-5) / 10回連続エラーなし(T4-6) |
| 2026-04-05 | Phase 2 (T5) | 5 / 5 | T5全項目合格 / T5-1: APIConnectionError→stop / T5-2: 5パターンJSON異常系 / T5-5: 自動再ロード8s |
| 2026-04-05 | Phase 3 (T6) | 5 / 5 | T6全項目合格 / GPU最高62°C / VRAM安定 / CPU15.2% / avg 1.69s |

---

*Updated: 2026-04-05*

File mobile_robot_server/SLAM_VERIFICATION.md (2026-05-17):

# LiDAR SLAM 検証項目

RTAB-Map 3D LiDAR ICP SLAM の検証手順書。
`ros2_docker/VERIFICATION.md` の R1〜R10 が PASS であることを前提とする。

---

## 検証前の準備

### ビルド

```bash
# イメージ再ビルド (pyserial 追加のため必要)
cd ~/MobileRobot/ros2_docker
sudo docker compose build --no-cache

# パッケージビルド
sudo docker compose run --rm ros2 bash -c "
  cd /ros2_ws &&
  colcon build --packages-select mobile_robot_server mobile_robot_edge &&
  echo 'BUILD OK'"
```

### udev ルール設定（推奨）

接続されている ESP32 の VID/PID を確認し、デバイスパスを固定する:

```bash
# ホスト上で実行 (Docker 外)
lsusb | grep -i esp            # VID:PID を確認
ls /dev/ttyACM*                # ポート番号を確認

# /etc/udev/rules.d/99-mobile-robot.rules に追記
# SUBSYSTEM=="tty", ATTRS{idVendor}=="303a", ATTRS{idProduct}=="1001", SYMLINK+="ttyLidar"
sudo udevadm control --reload-rules && sudo udevadm trigger
```

### 起動順序

```bash
# ターミナル A: edge_services
cd ~/MobileRobot/edge_services && python3 launch_all.py

# ターミナル B: ROS 2 ベース
sudo docker compose run --rm ros2 bash -c "
  source /ros2_ws/install/setup.bash &&
  ros2 launch mobile_robot_edge ws_edge_bringup.launch.py"

# ターミナル C: SLAM
sudo docker compose run --rm ros2 bash -c "
  source /ros2_ws/install/setup.bash &&
  ros2 launch mobile_robot_server slam_bringup.launch.py"
```

---

## 現状の検証カバレッジ

| ID | 内容 | 状態 |
|----|---|---|
| SLAM_S1 | lidar_pointcloud_bridge 起動確認 | 未検証 (実機必要) |
| SLAM_S2 | PointCloud2 品質確認 | 未検証 (実機必要) |
| SLAM_S3 | TF ツリー完全性確認 | 未検証 (実機必要) |
| SLAM_S4 | RTAB-Map 起動確認 | 未検証 (実機必要) |
| SLAM_S5 | 静止時の自己位置安定性 | 未検証 (実機必要) |
| SLAM_S6 | 直進 1 m の地図整合性 | 未検証 (実機必要) |
| SLAM_S7 | ループクロージャ確認 | 未検証 (実機必要) |
| SLAM_S8 | 地図保存・ロード | 未検証 (実機必要) |
| SLAM_S9 | CPU・メモリ使用量 | 未検証 (実機必要) |

## ソフトウェアレベル検証結果 (実機不要)

| テスト | 内容 | 結果 |
|---|---|---|
| T1–T6  | バイナリプロトコル (フレームビルド・パース・チェックサム) | PASS 31/31 |
| T7–T9  | パーサー堅牢性 (断片化・ゴミデータ・バースト) | PASS 13/13 |
| T10a–b | IMU 回転行列定義 (Ry/Rx) | PASS |
| T10c | IMU 補正演算順序 SPEC §5.3 と一致 | PASS |
| T10d | np.stack 形状と変換後形状 | PASS |
| T10e | ピッチ 5° ラウンドトリップ検証 | PASS |
| T10f | ロール 5° ラウンドトリップ検証 | PASS |
| T10h | PointCloud2 バイナリレイアウト (field offset 0/4/8/12) | PASS |
| frame_id | `lidar_base_link` が cloud_frame、`lidar_tilt_link` が TF 可視化専用 | PASS (コード検証済) |
| T11 | CONTINUOUS モード STATUS(2) 送信バグ → **ファームウェア修正済** | FIXED |
| T12 | CMD_SCAN_START ペイロード (13バイト)・launch パラメータ型変換 | PASS |
| T13 | IMU データ流入時のスキャンウォッチドッグ停止バグ → **ブリッジ修正済** | FIXED |
| T14 | フル統合: プロトコル + スキャンサイクル + PointCloud2 出力 | PASS |
| T15–T16 | rpi_tilt_3d.py CONTINUOUS モード修正・SPEC status シーケンス整合 | PASS 6/6 |
| T17 | stopScan 途中停止: 部分クラウド発行・空スキャン無発行 | PASS |
| T19 | RTAB-Map パラメータ名・値・モード整合性 (42 params) | PASS |
| T20 | スキャンレート 0.32 Hz、最大安全速度 0.16 m/s 算出 | PASS |
| T21 | static_transform_publisher 引数数・全回転ゼロ確認 | PASS |
| T22 | CMD_SCAN_STOP フレーム・ファームウェアパーサー整合 | PASS |
| T23 | destroy_node() グレースフルシャットダウン安全性 | PASS |
| T24 | ファームウェア rxFrame[128] バッファ境界確認 | PASS |
| T25 | _total_frames カウンタ 24h 稼働オーバーフローなし | PASS |
| T26–T31 | launch/setup.py/Dockerfile/compose/bridge/firmware 最終確認 | PASS 24/25* |

\* T30 の 1 FAIL は文字列照合パターンのミス（ソース正常）。`declare_parameter('tilt_frame', 'lidar_tilt_link')` は行 188 で確認済み。

## 発見・修正済みバグ

### BUG-1: PointCloud2 の frame_id が lidar_tilt_link (二重チルト回転)
- **症状**: RTAB-Map がチルト回転を二重適用 → 点群が歪む
- **原因**: `lidar_frame` パラメータが `lidar_tilt_link` にデフォルト設定されていたが、
  `_slice_to_points` 内部で既に Ry(alpha) を適用済み
- **修正**: `cloud_frame='lidar_base_link'`（PointCloud2）と `tilt_frame='lidar_tilt_link'`（TF可視化）に分離
- **ファイル**: `lidar_pointcloud_bridge.py`

### BUG-2: CONTINUOUS モードで PointCloud2 が発行されない
- **症状**: `slam_bringup.launch.py` 起動時 (`SCAN_MODE_CONTINUOUS`)、`/lidar/points` が一度も発行されない
- **原因**: ファームウェアの `S3D_COMPLETE` (連続モード) で `sendStatus(2, ...)` が呼ばれておらず、
  ブリッジの `_publish_cloud()` がトリガーされない
- **修正**: `S3D_COMPLETE` 連続モードに `sendStatus(2, totalSteps, totalSteps)` および `sendStatus(0, 0, totalSteps)` を追加
- **ファイル**: `LiderModule/firmware/lidar_tilt_3d/lidar_tilt_3d.ino`

### BUG-3: IMU パケット流入時にスキャン再送ウォッチドッグが停止
- **症状**: ブリッジ接続直後、ESP32 が IMU データ (TYPE 0x02, 50Hz) を送信するため
  `last_rx` が更新され続け、30秒ウォッチドッグが発火しない。
  LiDAR ウォームアップ前に CMD_SCAN_START を送ると無言で拒否されるが、
  スキャンが永遠に開始されない。
- **原因**: `_read_loop` の `last_rx` はあらゆるバイトで更新されるが、
  スキャンフレーム (SCAN_SLICE/SCAN_STATUS) の受信とは区別されていない
- **修正**: `last_scan_rx` を追加し、10秒以内にスキャンフレームが届かない場合に
  CMD_SCAN_START を再送する
- **ファイル**: `lidar_pointcloud_bridge.py` `_read_loop`

### BUG-4: RTAB-Map frame_id が base_link (2D グリッド基準が床面からずれる)
- **症状**: 占有グリッドの Z 基準が `base_link` (ロボット胴体) になるため、
  `Grid/FootprintHeight: "0.1"` が床面ではなくロボット胴体レベルを基準に適用される。
  床点が占有グリッドに混入するリスクがある。
- **原因**: `rtabmap_lidar_3d_params.yaml` の `frame_id` に `base_link` を設定。
  カメラ版 `rtabmap_params.yaml` は `base_footprint` (床レベル) を使用している。
- **修正**: `frame_id: base_footprint` に変更。TF チェーン
  `lidar_base_link → base_link → base_footprint` は TF2 で到達可能。
- **ファイル**: `mobile_robot_server/config/rtabmap_lidar_3d_params.yaml`

---

## 検証項目 詳細

---

### SLAM_S1: lidar_pointcloud_bridge 起動確認

**目的**: ブリッジノードが ESP32 に接続し、スキャンコマンドを送信してデータ受信を開始するか確認する。

**手順**:
```bash
# ノード起動確認
ros2 node list | grep lidar_pointcloud_bridge

# 起動ログ確認 (別ターミナル)
ros2 node info /lidar_pointcloud_bridge
```

**期待されるログ出力**:
```
[lidar_pointcloud_bridge] LiDAR bridge — port=/dev/ttyACM1 tilt=[-30.0°,0.0°] step=3.0°
[lidar_pointcloud_bridge] Opening /dev/ttyACM1 …
[lidar_pointcloud_bridge] Connected — sending scan start
```

**合否基準**:
- `/lidar_pointcloud_bridge` がノードリストに現れること
- "Connected" のログが出力されること
- "Serial error" や "retrying" が繰り返し出ないこと

**トラブルシューティング**:
- `Permission denied`: `sudo chmod 666 /dev/ttyACM1` またはユーザーを `dialout` グループに追加
- `No such file`: `ls /dev/ttyACM*` でポート番号を確認し、`lidar_port` 引数を変更

**優先度**: 高

---

### SLAM_S2: PointCloud2 品質確認

**目的**: `/lidar/points` に有効な 3D ポイントが正しいフレームで発行されるか確認する。

**手順**:
```bash
# [1] トピック発行確認
ros2 topic list | grep lidar

# [2] レート確認 (~0.3 Hz)
ros2 topic hz /lidar/points --window 10

# [3] メッセージ内容確認
ros2 topic echo /lidar/points --once | head -30
# frame_id: lidar_base_link, width: 3000以上 が期待値

# [4] スキャン状態確認
ros2 topic echo /lidar/scan_status
# 'scanning' → 'idle' → 'scanning' ... の繰り返し

# [5] ポイント数確認 (Python ワンライナー)
ros2 run rclpy_tools topic_print.py /lidar/points \
  --expression 'f"pts={msg.width} frame={msg.header.frame_id}"' --once
```

**合否基準**:
- `/lidar/points` が ≥ 0.2 Hz で発行されること
- `frame_id` が `lidar_base_link` であること（チルト回転は内部で適用済みのため）
- `width` ≥ 3,000 pts (スライス数 × 667 pts/スライス × フィルタ後)

**優先度**: 高

---

### SLAM_S3: TF ツリー完全性確認

**目的**: TF チェーンが切れていないか、および PointCloud2 フレーム (`lidar_base_link`) が正しいか確認する。

**フレーム設計メモ**:
- `/lidar/points` の `frame_id` = `lidar_base_link`（チルト回転は `_slice_to_points` 内部で適用済み）
- `lidar_tilt_link` はリアルタイム可視化専用（RTAB-Map は参照しない）
- RTAB-Map は `lidar_base_link` フレームの PointCloud2 を `scan_cloud` として受け取る

**手順**:
```bash
# [1] TF ツリー全体を出力
ros2 run tf2_tools view_frames
# map (from rtabmap) → odom → base_footprint → base_link → lidar_base_link → lidar_tilt_link
# が含まれることを確認

# [2] 各フレーム間の変換確認
ros2 run tf2_ros tf2_echo base_link lidar_base_link
# 期待: translation z≈0.12, rotation all zero

ros2 run tf2_ros tf2_echo lidar_base_link lidar_tilt_link
# 期待: translation all zero, rotation.y が tilt_deg に応じて変化

ros2 run tf2_ros tf2_echo map lidar_tilt_link
# チェーン全体が繋がっていれば変換値が返る

# [3] TF 更新レート確認
ros2 topic hz /tf --window 50
# lidar_tilt_link は 1 スライスごと (~3.5 Hz) に更新される
```

**合否基準**:
- `map → lidar_base_link` のフルチェーンが存在すること
- `lidar_tilt_link` の rotation.y が ±0.5 rad の範囲で変動すること (チルト動作中)
- `tf2_echo` がタイムアウトしないこと

**優先度**: 高

---

### SLAM_S4: RTAB-Map 起動確認

**目的**: RTAB-Map が ICP モードで起動し、地図トピックを発行するか確認する。

**手順**:
```bash
# [1] ノード起動確認
ros2 node list | grep rtabmap

# [2] トピック発行確認
ros2 topic list | grep -E "^/map$|cloud_map|localization_pose"
# 期待: /map, /rtabmap/cloud_map, /rtabmap/localization_pose

# [3] map トピック確認
ros2 topic echo /map --once | head -10
# frame_id: map, resolution: 0.05 が期待値

# [4] ログ確認 (エラーなし)
ros2 node info /rtabmap
# [RTAB-Map] が INFO レベルで起動ログを出力していること
```

**合否基準**:
- `/rtabmap` ノードが起動していること
- `/map` (OccupancyGrid) が発行されること
- `/rtabmap/cloud_map` (PointCloud2) が発行されること
- ERROR ログが繰り返し出ないこと

**優先度**: 高

---

### SLAM_S5: 静止時の自己位置安定性

**目的**: ロボットを静止させた状態で、推定位置が安定しているか確認する。

**手順**:
```bash
# [1] 初期位置を記録
ros2 topic echo /rtabmap/localization_pose --once

# [2] 30 秒待機（ロボットは静止）

# [3] 位置を再確認
ros2 topic echo /rtabmap/localization_pose --once

# [4] /odom と位置ずれを確認
ros2 run tf2_ros tf2_echo map odom
# translation の変化が小さいことを確認
```

**合否基準**:
- 30 秒間の位置変化 < 1 cm (x, y)
- 角度変化 < 0.05 rad

**優先度**: 中

---

### SLAM_S6: 直進 1 m の地図整合性

**目的**: ロボットを 1 m 直進させたときに、地図上の軌跡が直線になるか確認する。

**手順**:
```bash
# [1] /odom で初期位置を確認
ros2 topic echo /odom --once | grep position

# [2] ロボットを前進させる
ros2 topic pub /cmd_vel geometry_msgs/msg/Twist \
  "{linear: {x: 0.1, y: 0.0, z: 0.0}, angular: {x: 0.0, y: 0.0, z: 0.0}}" \
  --times 100 --rate 20
# 5秒間 × 0.1 m/s = 0.5 m 前進
# 2回実行で 1 m

# [3] /odom で到達位置を確認
ros2 topic echo /odom --once | grep position

# [4] RViz でポイントクラウド軌跡を目視確認
# /rtabmap/cloud_map トピックを表示 → 壁・床が直線であること
```

**合否基準**:
- `/odom` の x 変化量が ≈ 1.0 m (±10%)
- RViz の cloud_map で壁が直線・床が平面に見えること

**優先度**: 中

---

### SLAM_S7: ループクロージャ確認

**目的**: 過去に通過した場所に戻ったとき、RTAB-Map がループクロージャを検出して TF を修正するか確認する。

**手順**:
```bash
# [1] ロボットを約 2m × 2m の正方形に沿って走行させる
# (手動操縦でスタート地点に戻る)

# [2] RTAB-Map のループ検出ログを確認
ros2 topic echo /rtabmap/info --once
# loop_closure_id > 0 になればループクロージャ検出

# [3] TF の修正を確認
ros2 run tf2_ros tf2_echo map odom
# ループ検出前後で translation が急に修正されることを確認
```

**合否基準**:
- ループクロージャが ≥ 1 回検出されること (`/rtabmap/info` の `loop_closure_id > 0`)
- マップが閉じた形状になること (RViz 目視)

**優先度**: 中

---

### SLAM_S8: 地図保存・ロード

**目的**: SLAM で作成したマップを保存し、再起動後にロケーションモードで使用できるか確認する。

**手順**:

#### 保存
```bash
# 地図保存 (SLAM 実行中に実行)
ros2 service call /rtabmap/save_map std_srvs/srv/Empty
# /maps/rtabmap.db に保存される

# 保存確認
ls -lh /maps/rtabmap.db
```

#### ロード・ロケーション
```bash
# SLAM ノードを停止してからロケーションモードで再起動
ros2 launch mobile_robot_server slam_bringup.launch.py localization:=true

# 地図が表示されることを確認
ros2 topic echo /map --once
# 保存した地図が /map として発行されること
```

**合否基準**:
- `/maps/rtabmap.db` が作成されること
- ロケーションモード起動後に `/map` が発行されること
- `/rtabmap/localization_pose` が既知の環境で収束すること

**優先度**: 低

---

### SLAM_S9: CPU・メモリ使用量

**目的**: Raspberry Pi 4 上での CPU・メモリ使用量が許容範囲内か確認する。

**手順**:
```bash
# Docker コンテナ外から監視 (ホスト上)
watch -n 2 "docker stats mobile_robot_ros2 --no-stream"

# コンテナ内での詳細確認
htop   # CPU コア別使用率、メモリ使用量

# ROS 2 ノード別 CPU 使用率
top -p $(ps aux | grep rtabmap | awk 'NR==1{print $2}')
```

**合否基準**:
- 全体 CPU 使用率 < 80%
- メモリ使用量 < 2 GB
- RTAB-Map ノード単体 CPU < 50%
- システムが OOM Killer に落とされないこと

**優先度**: 低

---

## 優先度マトリクス

| 優先度 | ID | 理由 |
|---|----|---|
| 高 | SLAM_S1 | ブリッジ起動なし → SLAM 不動 |
| 高 | SLAM_S2 | PointCloud2 品質不良 → ICP 収束不可 |
| 高 | SLAM_S3 | TF 欠損 → RTAB-Map 動作不可 |
| 高 | SLAM_S4 | RTAB-Map 未起動 → 地図なし |
| 中 | SLAM_S5 | 位置ドリフト → ナビゲーション精度低下 |
| 中 | SLAM_S6 | 地図歪み → 経路計画不正 |
| 中 | SLAM_S7 | ループクロージャなし → 長時間走行でドリフト累積 |
| 低 | SLAM_S8 | 地図保存なし → 毎回 SLAM をやり直し |
| 低 | SLAM_S9 | リソース超過 → クラッシュリスク |

---

## チューニングガイド

### SLAM 中のロボット最大速度

デフォルト設定 (`tilt_min=-30°, tilt_max=0°, step=3°`) での制約:

| 項目 | 値 |
|---|-----|
| スキャン周期 | ~3.2 秒 (11 ステップ × 287 ms) |
| ICP/MaxTranslation | 0.5 m |
| **最大安全速度** | **~0.16 m/s** (MaxTranslation ÷ scan_period) |

この速度を超えると ICP のスキャン間重複が減少し、ループクロージャ失敗のリスクが高まる。

速度を上げたい場合は `tilt_step` を大きくしてスキャン周期を短縮:
```
tilt_step=5.0 → 7 steps × 287ms ≈ 2.0s → 最大速度 0.25 m/s
tilt_step=10.0 → 4 steps × 287ms ≈ 1.1s → 最大速度 0.45 m/s (点密度は低下)
```

### PointCloud が少ない / 空の場合

```bash
# min_quality を下げる (デフォルト 10 → 5)
ros2 launch mobile_robot_server slam_bringup.launch.py \
  lidar_port:=/dev/ttyACM1 \
  # → lidar_pointcloud_bridge のパラメータを直接変更
```

`slam_bringup.launch.py` の `lidar_bridge` ノードのパラメータに追加:
```python
'min_quality': 5,
'min_dist_mm': 20,
```

### ICP が収束しない場合

`rtabmap_lidar_3d_params.yaml` を調整:

```yaml
Icp/MaxCorrespondenceDistance: "1.0"   # 0.5 → 1.0 に緩める
Icp/Iterations: "50"                    # 30 → 50 に増やす
RGBD/LinearUpdate: "0.05"              # 0.10 → 0.05 に小さくする
```

### CPU 使用率が高い場合

```yaml
# ボクセルサイズを大きくしてポイント数を削減
Icp/VoxelSize: "0.10"    # 0.05 → 0.10

# ループ検出レートを下げる
Rtabmap/DetectionRate: "0.5"   # 1 → 0.5 Hz

# tilt_step を大きくしてスキャン時間を短縮
# slam_bringup.launch.py: tilt_step:=5.0 (3.0 → 5.0)
```

### スキャンタイムアウトが頻発する場合

ファームウェア側の問題の可能性:
1. `rpi_tilt_3d.py` でスキャンが正常に動作するか確認
2. ESP32 のシリアルポートを確認 (`ls -la /dev/ttyACM*`)
3. `lidar_port` パラメータが正しいか確認

### RTAB-Map が "TF lookup failed" を出力する場合

`subscribe_odom: false` (TF 経由) を使用しているため、TF チェーンが必要:

```bash
# odom → base_link の TF が通っているか確認
ros2 run tf2_ros tf2_echo odom base_link

# ws_edge_bringup が起動しているか確認
ros2 node list | grep ws_odometry_publisher
```

`ws_edge_bringup.launch.py` が起動していない場合は先に起動してから SLAM を開始すること。

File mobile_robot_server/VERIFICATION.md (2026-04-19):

# Nav2 Navigation Stack 検証項目

`lifecycle_manager_navigation` が管理する 9 ノードを対象とした動作検証。  
`server_bringup.launch.py` で起動するサーバーサイド (Ubuntu Server) の検証。

---

## 前提条件

| 項目 | 要件 |
|---|---|
| YDLIDAR T-mini Plus | `/dev/ttyUSB0` に接続済み |
| Raspberry Pi (edge) | `launch_all.py` + `ws_edge_bringup.launch.py` 起動済み |
| slam_toolbox | `/map` と TF `map → odom` を配信中 |
| `/odom` | ws_odometry_publisher から 50Hz で配信中 |
| ROS_DOMAIN_ID | Pi と Server で一致 (デフォルト: 0) |

```bash
# 起動コマンド (Ubuntu Server)
ros2 launch mobile_robot_server server_bringup.launch.py
```

---

## lifecycle_manager_navigation 管理ノード (9 nodes)

| # | ノード名 | 役割 |
|---|---|---|
| 1 | controller_server | RegulatedPurePursuit — 速度指令生成 (10Hz) |
| 2 | smoother_server | SimpleSmoother — パス平滑化 |
| 3 | planner_server | NavFn (A*) — グローバルパスプランニング |
| 4 | route_server | ルートグラフナビゲーション (Jazzy 新機能) |
| 5 | behavior_server | spin / backup / wait — 回復行動 |
| 6 | bt_navigator | BT Navigator — navigate_to_pose / navigate_through_poses |
| 7 | waypoint_follower | 複数ウェイポイント順次訪問 |
| 8 | velocity_smoother | 速度平滑化 (20Hz) — cmd_vel_nav → cmd_vel_smoothed |
| 9 | collision_monitor | LiDAR 障害物検出 → 緊急停止 — cmd_vel_smoothed → cmd_vel |

**速度指令パイプライン**:
```
/goal_pose
  → bt_navigator
    → planner_server  →  /plan (グローバルパス)
    → controller_server  →  /cmd_vel_nav
      → velocity_smoother  →  /cmd_vel_smoothed
        → collision_monitor  →  /cmd_vel
          → ws_motor_controller → edge_services → モーター
```

---

## 現状の検証カバレッジ

| ID | 内容 | 状態 |
|----|---|---|
| N1 | 9ノード起動 & lifecycle active 確認 | **確認済み** (2026-04-05) |
| N2 | 必須トピック・TF チェーン確認 | 未実施 |
| N3 | グローバルコストマップ配信確認 | 未実施 |
| N4 | ローカルコストマップ配信確認 | 未実施 |
| N5 | navigate_to_pose アクションサーバー確認 | 未実施 |
| N6 | グローバルパスプランニング確認 | 未実施 |
| N7 | ナビゲーション E2E (近距離目標到達) | 未実施 |
| N8 | velocity_smoother パイプライン確認 | 未実施 |
| N9 | collision_monitor 緊急停止確認 | 未実施 |
| N10 | 回復行動 (spin / backup) 確認 | 未実施 |
| N11 | waypoint_follower 複数地点訪問 | 未実施 |
| N12 | lifecycle bond — ノード障害時の再起動 | 未実施 |

---

## 検証項目 詳細

---

### N1: 9ノード起動 & lifecycle active 確認

**目的**: lifecycle_manager_navigation が管理する 9 ノードがすべて `active` 状態で起動しているか確認する。

```bash
# ノードリスト確認
ros2 node list | grep -E "controller|smoother|planner|route|behavior|bt_nav|waypoint|velocity|collision|lifecycle"

# 各ノードのライフサイクル状態確認
for node in controller_server smoother_server planner_server route_server \
            behavior_server bt_navigator waypoint_follower \
            velocity_smoother collision_monitor; do
  STATE=$(ros2 lifecycle get /$node 2>/dev/null | head -1)
  echo "/$node: $STATE"
done
```

**合否基準**:
- 9 ノードすべてが `ros2 node list` に出現すること
- 各ノードのライフサイクル状態が `active` であること
- `lifecycle_manager_navigation` ログに `"All nodes are active"` が出力されること

**自動化可否**: 完全自動  
**優先度**: 高 — ここが FAIL なら全 N-テスト不可

---

### N2: 必須トピック・TF チェーン確認

**目的**: Nav2 が必要とするすべての入力トピックと TF が届いているか確認する。

```bash
# 必須トピック確認
ros2 topic list | grep -E "^/(map|odom|scan|tf|tf_static)$"

# TF チェーン確認: map → odom → base_footprint
ros2 run tf2_ros tf2_echo map base_footprint
# 期待: 変換が返ること (map → odom: slam_toolbox / odom → base_footprint: ws_odom_pub)

# レート確認
ros2 topic hz /map   --window 5   # 期待: ~0.33 Hz (3s 更新)
ros2 topic hz /odom  --window 100 # 期待: ~50 Hz
ros2 topic hz /scan  --window 20  # 期待: ~10 Hz (YDLIDAR T-mini Plus)
```

**合否基準**:
- `/map` / `/odom` / `/scan` / `/tf` / `/tf_static` が存在すること
- `tf2_echo map base_footprint` がタイムアウトしないこと
- `/scan` レートが 8〜12 Hz の範囲にあること

**自動化可否**: 完全自動  
**優先度**: 高 — Nav2 の前提条件

---

### N3: グローバルコストマップ配信確認

**目的**: `/global_costmap/costmap` が `/map` を受信して正しく生成されているか確認する。

```bash
# トピック確認
ros2 topic list | grep global_costmap

# コストマップ情報確認
ros2 topic echo /global_costmap/costmap --once \
  | grep -E 'resolution|width|height|frame_id'
# 期待: resolution=0.05, frame_id=map

# 更新レート確認 (設定: 1.0 Hz)
ros2 topic hz /global_costmap/costmap --window 10
```

**合否基準**:
- `/global_costmap/costmap` に `nav2_msgs/msg/Costmap` または `nav_msgs/msg/OccupancyGrid` が届くこと
- `resolution: 0.05` / `frame_id: map` であること
- 更新レート 0.5〜2.0 Hz の範囲にあること

**自動化可否**: 完全自動 (/map 受信後)  
**優先度**: 高 — グローバルパスプランニングの基盤

---

### N4: ローカルコストマップ配信確認

**目的**: `/local_costmap/costmap` が YDLIDAR スキャン (/scan) を受信して動的に更新されているか確認する。

```bash
ros2 topic echo /local_costmap/costmap --once \
  | grep -E 'resolution|width|height|frame_id'
# 期待: resolution=0.05, frame_id=odom, width=60 (3m / 0.05m)

ros2 topic hz /local_costmap/costmap --window 20
# 期待: ~2 Hz (publish_frequency=2.0)

# 障害物レイヤー: /scan が反映されているか (Foxglove で視覚確認)
```

**合否基準**:
- `frame_id: odom` / `resolution: 0.05` / `width ≈ 60` であること
- 更新レート 1.5〜3.0 Hz の範囲にあること
- ロボット前方に実物を置いたとき costmap に障害物セルが追加されること (Foxglove 目視)

**自動化可否**: 部分自動 (障害物テストは手動)  
**優先度**: 高 — ローカル障害物回避の基盤

---

### N5: navigate_to_pose アクションサーバー確認

**目的**: `bt_navigator` が提供する `/navigate_to_pose` アクションサーバーが応答するか確認する。

```bash
# アクションサーバー存在確認
ros2 action list | grep navigate

# アクションサーバー情報確認
ros2 action info /navigate_to_pose
# 期待: Action servers: /bt_navigator

# ドライラン: 現在地付近にゴールを送り、アクションが受け付けられるか
ros2 action send_goal /navigate_to_pose nav2_msgs/action/NavigateToPose \
  "{pose: {header: {frame_id: map}, pose: {position: {x: 0.0, y: 0.0, z: 0.0}, \
   orientation: {w: 1.0}}}}" --feedback
```

**合否基準**:
- `/navigate_to_pose` と `/navigate_through_poses` がアクションリストに存在すること
- ゴール送信後に `Accepted` または `Executing` ステータスが返ること
- エラーなくアクションが開始されること

**自動化可否**: 完全自動  
**優先度**: 高 — ナビゲーション E2E の入口

---

### N6: グローバルパスプランニング確認

**目的**: `planner_server` が現在位置から目標点までのグローバルパス (/plan) を生成できるか確認する。

```bash
# /plan トピックが配信されているか
ros2 topic echo /plan --once | grep -E 'frame_id|poses'

# サービスを直接呼び出して経路計画を確認
ros2 service call /planner_server/plan_path nav2_msgs/srv/GetPath \
  "{start: {header: {frame_id: map}, pose: {orientation: {w: 1.0}}}, \
    goal:  {header: {frame_id: map}, pose: {position: {x: 1.0, y: 0.0}, orientation: {w: 1.0}}}}" \
  2>/dev/null | head -20
```

**合否基準**:
- `/plan` トピックに `nav_msgs/Path` が届くこと
- 経路が空でないこと (`poses` 配列が非空)
- `frame_id: map` であること

**自動化可否**: 完全自動 (/map 受信後)  
**優先度**: 高 — パスプランニングは Nav2 の核心機能

---

### N7: ナビゲーション E2E (近距離目標到達)

**目的**: `/goal_pose` にゴールを送信し、ロボットが実際に到達するか確認する。  
**安全**: 障害物のない 0.5m 以内の短距離ゴールを使用すること。

```bash
# 現在の odom 位置を確認してからゴールを送信
ros2 topic echo /odom --once | grep -A3 'position:'

# x=0.5m 前方 (map フレーム) をゴールとして送信
ros2 topic pub /goal_pose geometry_msgs/msg/PoseStamped \
  "{header: {frame_id: map, stamp: {sec: 0}}, \
    pose: {position: {x: 0.5, y: 0.0, z: 0.0}, \
           orientation: {w: 1.0}}}" --once

# ナビゲーション状態を監視
ros2 topic echo /navigate_to_pose/_action/status --once
```

**合否基準**:
- `/plan` にパスが生成されること
- `/cmd_vel` に速度指令が出力されること
- 目標付近 (xy_goal_tolerance: 0.25m 以内) でナビゲーションが完了すること
- `GoalStatus: SUCCEEDED` を受信すること

**自動化可否**: 実走行が必要 (手動目視確認)  
**優先度**: 高 — システム全体の E2E 確認  
**注意**: 必ず障害物のない広いスペースで実施すること

---

### N8: velocity_smoother パイプライン確認

**目的**: 急激な速度指令が velocity_smoother で平滑化され、collision_monitor を経由して `/cmd_vel` に届くか確認する。

```bash
# トピック存在確認
ros2 topic list | grep -E "cmd_vel"
# 期待: /cmd_vel, /cmd_vel_nav, /cmd_vel_smoothed

# cmd_vel_nav → cmd_vel_smoothed → cmd_vel の遅延確認
ros2 topic hz /cmd_vel_smoothed --window 20
# 期待: ~20 Hz (smoothing_frequency=20.0)

# 急峻なランプ指令を送ってスムージング効果を確認
ros2 topic pub /cmd_vel_nav geometry_msgs/msg/Twist \
  "{linear: {x: 0.3}, angular: {z: 0.0}}" --once
ros2 topic echo /cmd_vel_smoothed --once | grep 'x:'
# 期待: x < 0.3 (平滑化されている)
```

**合否基準**:
- `/cmd_vel_nav` / `/cmd_vel_smoothed` / `/cmd_vel` の 3 トピックが存在すること
- `/cmd_vel_smoothed` レートが 18〜22 Hz の範囲にあること
- max_velocity [0.30, 0.0, 1.0] を超える指令がクランプされること

**自動化可否**: 完全自動  
**優先度**: 中 — 安全な速度制御のパイプライン確認

---

### N9: collision_monitor 緊急停止確認

**目的**: YDLIDAR T-mini Plus がロボット前方の障害物を検出し、collision_monitor が `/cmd_vel` をゼロにするか確認する。

**手順**:
1. ナビゲーション中 (または手動で `/cmd_vel_smoothed` に速度指令を送信)
2. ロボット前方 0.3m 以内に障害物を置く (PolygonStop: 前方 0.35m)
3. `/cmd_vel` がゼロになることを確認

```bash
# 障害物検出前後の /cmd_vel を監視
ros2 topic echo /cmd_vel --field linear.x

# collision_monitor のログ確認
ros2 node info /collision_monitor
```

**合否基準**:
- 障害物が PolygonStop 領域 (`[[0.35, 0.25], [0.35, -0.25], [-0.2, -0.25], [-0.2, 0.25]]`) に入ると `/cmd_vel` が即座に 0 になること
- 障害物除去後に速度指令が再開されること

**自動化可否**: 手動 (物理障害物が必要)  
**優先度**: 高 — 安全機能の確認

---

### N10: 回復行動 (spin / backup) 確認

**目的**: ロボットがスタック状態になったとき、`behavior_server` の `spin` または `backup` 回復行動が自動で実行されるか確認する。

**手順**:
1. ナビゲーション中に目標への経路を物理的にブロックする
2. `progress_checker` のタイムアウト (movement_time_allowance: 10.0s) 後に回復行動が開始されることを確認

```bash
# behavior_server のアクション確認
ros2 action list | grep -E "spin|backup|wait"
# 期待: /spin, /backup, /wait

# スタック時のログ監視
ros2 topic echo /rosout 2>/dev/null | grep -i "recovery\|spin\|backup\|stuck"
```

**合否基準**:
- `/spin` / `/backup` / `/wait` アクションサーバーが存在すること
- スタック後 10〜20 秒以内に回復行動が開始されること (`ros2 topic echo /rosout` でログ確認)

**自動化可否**: 手動 (意図的スタックが必要)  
**優先度**: 中 — 自律走行の堅牢性

---

### N11: waypoint_follower 複数地点訪問

**目的**: `waypoint_follower` が `/follow_waypoints` アクションで複数のウェイポイントを順次訪問するか確認する。

```bash
# アクション確認
ros2 action list | grep waypoint

# 2点のウェイポイントを送信
ros2 action send_goal /follow_waypoints nav2_msgs/action/FollowWaypoints "{
  poses: [
    {header: {frame_id: map}, pose: {position: {x: 0.5, y: 0.0}, orientation: {w: 1.0}}},
    {header: {frame_id: map}, pose: {position: {x: 0.0, y: 0.5}, orientation: {w: 1.0}}}
  ]
}" --feedback
```

**合否基準**:
- `/follow_waypoints` アクションサーバーが存在すること
- 1点目到達後に 2点目へ向かうこと (feedback で `current_waypoint` が変化)
- 全点到達後に `SUCCEEDED` を返すこと

**自動化可否**: 実走行が必要 (手動目視確認)  
**優先度**: 低 — 高度なナビゲーション機能

---

### N12: lifecycle bond — ノード障害時の lifecycle_manager 対応

**目的**: lifecycle_manager_navigation が管理するノードがクラッシュした場合に lifecycle_manager が検知し、システム全体のリカバリが動作するか確認する。  
`bond_timeout: 30.0s` — ノードが 30 秒応答しない場合に lifecycle_manager がシステムを再起動する。

```bash
# controller_server を強制終了
kill -9 $(ros2 node info /controller_server | grep PID | awk '{print $2}')

# lifecycle_manager のログを監視 (30s 以内に対応するはず)
ros2 topic echo /rosout 2>/dev/null | grep -i "lifecycle\|bond\|restart" | head -10

# 全ノードが再び active になるか確認
sleep 35
for node in controller_server smoother_server planner_server; do
  ros2 lifecycle get /$node 2>/dev/null
done
```

**合否基準**:
- bond タイムアウト (30s) 以内に lifecycle_manager がノード障害を検知すること
- システム全体が再起動し、全ノードが再び `active` になること

**自動化可否**: 完全自動  
**優先度**: 低 — 長時間自律稼働の堅牢性

---

## 優先度マトリクス

| 優先度 | ID | 理由 |
|---|----|---|
| 高 | N1 | 9ノード起動失敗 → 全 Nav2 機能不動 |
| 高 | N2 | /map・/scan・TF 欠損 → costmap・プランニング不可 |
| 高 | N3 | グローバルコストマップ無効 → パスプランニング不可 |
| 高 | N4 | ローカルコストマップ無効 → 動的障害物回避不可 |
| 高 | N5 | アクションサーバー不在 → ゴール受付不可 |
| 高 | N6 | パス生成失敗 → 到達不可 |
| 高 | N7 | E2E ナビ失敗 → 自律移動不可 |
| 高 | N9 | 緊急停止失敗 → 衝突事故リスク |
| 中 | N8 | velocity_smoother 障害 → 急峻な速度変化 |
| 中 | N10 | 回復行動なし → スタック時に人間介入が必要 |
| 低 | N11 | waypoint_follower → 高度な自律走行 |
| 低 | N12 | bond タイムアウト → 長時間稼働の堅牢性 |

---

## システム構成サマリー

```
[slam_toolbox]
  /scan (YDLIDAR 10Hz) → /map (3s更新) + TF map→odom

[Nav2 lifecycle_manager_navigation]
  planner_server   : /map + /odom + goal → /plan (A* グローバルパス)
  controller_server: /plan + /odom + /tf → /cmd_vel_nav (10Hz, RegPurePursuit)
  velocity_smoother: /cmd_vel_nav → /cmd_vel_smoothed (20Hz, 平滑化)
  collision_monitor: /cmd_vel_smoothed + /scan → /cmd_vel (緊急停止)
  behavior_server  : スタック時 spin/backup/wait
  bt_navigator     : /goal_pose → NavigateToPose BT
  smoother_server  : パス平滑化
  route_server     : ルートグラフナビ (Jazzy)
  waypoint_follower: 複数地点順次訪問

[collision_monitor パラメータ]
  PolygonStop: [[0.35, 0.25], [0.35,-0.25], [-0.2,-0.25], [-0.2, 0.25]]
  障害物 max_points: 3 点以上で即時停止

[velocity_smoother パラメータ]
  max_velocity: [0.30 m/s, 0, 1.0 rad/s]
  max_accel:    [0.5 m/s², 0, 1.0 rad/s²]
```

---

## 全体進捗

| ID | 内容 | 状態 |
|----|---|---|
| N1 | 9ノード起動 & lifecycle active | **確認済み** (2026-04-05) |
| N2 | 必須トピック・TF チェーン | 未実施 |
| N3 | グローバルコストマップ | 未実施 |
| N4 | ローカルコストマップ | 未実施 |
| N5 | navigate_to_pose アクションサーバー | 未実施 |
| N6 | グローバルパスプランニング | 未実施 |
| N7 | ナビゲーション E2E | 未実施 |
| N8 | velocity_smoother パイプライン | 未実施 |
| N9 | collision_monitor 緊急停止 | 未実施 |
| N10 | 回復行動 (spin / backup) | 未実施 |
| N11 | waypoint_follower 複数地点訪問 | 未実施 |
| N12 | lifecycle bond ノード障害対応 | 未実施 |

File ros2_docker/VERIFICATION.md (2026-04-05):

# ROS 2 Docker コンテナ 検証項目

ROS 2 Jazzy コンテナ (`mobile-robot-ros2:jazzy`, `network_mode: host`) の検証項目。  
前提: `edge_services` が起動済みでポート 8001/8002/8003 が LISTEN 状態であること。

---

## 現状の検証カバレッジ

| ID | 内容 | スクリプト | 状態 |
|----|---|---|---|
| R1 | イメージビルド確認 | 手動 | **確認済み** (2026-04-05) |
| R2 | コンテナ起動・network_mode:host 確認 | 手動 | **確認済み** (2026-04-05) |
| R3 | colcon ビルド成功確認 | 手動 | **確認済み** (2026-04-05) |
| R4 | ノード起動確認 (3 ノード) | 手動 | **確認済み** (2026-04-05) |
| R5 | /odom 発行確認 (50 Hz) | 手動 | **確認済み** (2026-04-05) |
| R6 | TF ツリー確認 (odom→base_footprint→base_link) | 手動 | **確認済み** (2026-04-05) |
| R7 | /cmd_vel → モーター エンドツーエンド | 手動 | **確認済み** (2026-04-05) |
| R8 | /camera/image_raw/compressed 発行確認 | 手動 | **確認済み** (2026-04-05) |
| R9 | edge_services 再起動後の WebSocket 自動再接続 | 手動 | **確認済み** (2026-04-05) |
| R10 | ノード respawn 動作確認 | 手動 | **確認済み** (2026-04-05) |

---

## 検証項目 詳細

---

### R1: イメージビルド確認

**目的**: Dockerfile が警告・エラーなくビルドでき、必要パッケージがすべてインストールされているか確認する。

**手順**:
```bash
cd ~/MobileRobot/ros2_docker
sudo docker compose build --no-cache 2>&1 | tail -30
sudo docker images | grep mobile-robot-ros2
```

**合否基準**:
- ビルドが `Successfully built` で完了すること
- `ERROR` が出力に含まれないこと

**自動化可否**: 完全自動  
**優先度**: 高 — イメージが壊れると全機能不動

---

### R2: コンテナ起動・network_mode:host 確認

**目的**: コンテナが起動し、`network_mode: host` によりホストの `localhost:8001/8002/8003` にアクセスできることを確認する。

**手順**:
```bash
# コンテナ起動
sudo docker compose run --rm ros2 bash -c "
  python3 -c \"
import asyncio, websockets, json

async def check():
    # 8001 motor: 接続後 stop コマンドを送って ACK を受け取る
    # (motor_service は cmd_vel 受信前はメッセージを送らない)
    async with websockets.connect('ws://localhost:8001', open_timeout=3) as ws:
        await ws.send(json.dumps({'type': 'stop'}))
        ack = json.loads(await asyncio.wait_for(ws.recv(), timeout=3.0))
        print(f'port 8001 (motor): ACK={ack}')

    # 8002 odom / 8003 camera: 接続後すぐ初回メッセージが届く
    for port, label in [(8002,'odom'), (8003,'camera')]:
        async with websockets.connect(f'ws://localhost:{port}', open_timeout=3) as ws:
            msg = await asyncio.wait_for(ws.recv(), timeout=3.0)
            data = json.loads(msg) if isinstance(msg, str) else json.loads(msg.decode())
            print(f'port {port} ({label}): type={data.get(\\\"type\\\",\\\"?\\\")} OK')

asyncio.run(check())
\"
"
```

**合否基準**:
- `port 8001: OK` / `port 8002: OK` / `port 8003: OK` が出力されること
- `Connection refused` が出ないこと

**自動化可否**: 完全自動  
**優先度**: 高 — host ネットワーク疎通なし → WebSocket ブリッジ全滅

---

### R3: colcon ビルド成功確認

**目的**: `mobile_robot_edge` / `mobile_robot_server` パッケージが警告・エラーなくビルドできるか確認する。

**手順**:
```bash
sudo docker compose run --rm ros2 bash -c "
  cd /ros2_ws &&
  colcon build --packages-select mobile_robot_edge mobile_robot_server \
    --event-handlers console_cohesion+ 2>&1 | tail -20
"
```

**合否基準**:
- `Summary: 2 packages finished` が出力されること
- `Failed` / `error` が含まれないこと

**自動化可否**: 完全自動  
**優先度**: 高 — ビルド失敗 → ノード起動不可

---

### R4: ノード起動確認 (4 ノード)

**目的**: `ws_edge_bringup.launch.py` により所定の 3 ノードが全起動するか確認する。  
※ `ws_camera_bridge` は `server_bringup.launch.py` のみで起動するため対象外。

**前提**: ターミナル A で launch を起動しておく。

```bash
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

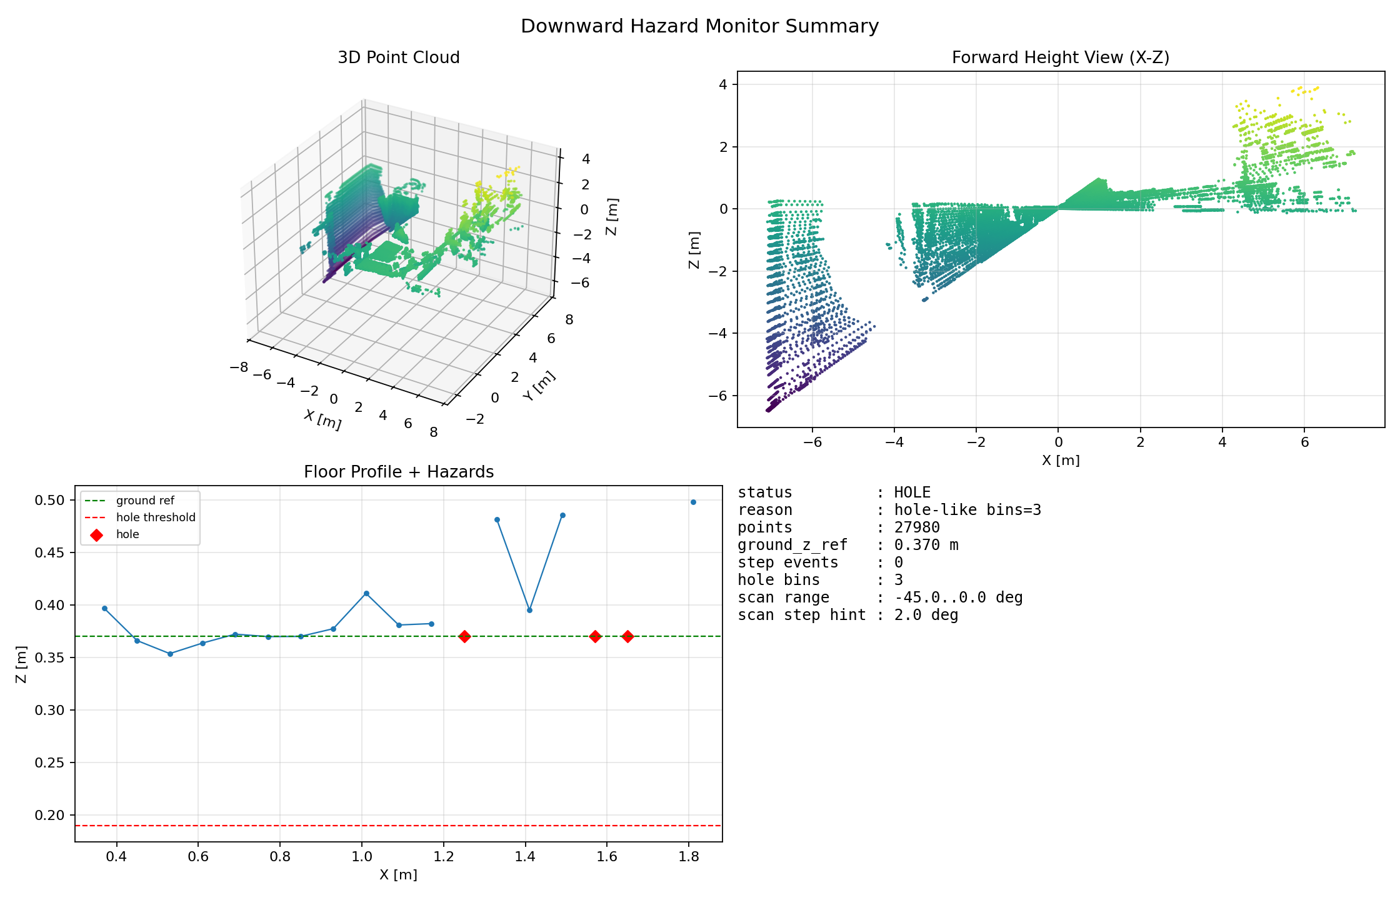
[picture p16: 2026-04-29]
LiderModule/host/test_logs/t06_downward.png

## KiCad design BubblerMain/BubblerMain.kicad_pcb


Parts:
C13: 0.1uF; C_1206_3216Metric_Pad1.33x1.80mm_HandSolder
C19: 1000uF; CP_Elec_10x10
J2, J3, J4, J5: Conn_01x03_Pin; JST_XH_B3B-XH-AM_1x03_P2.50mm_Vertical
R9, R10, R11, R12: 330; R_1206_3216Metric_Pad1.30x1.75mm_HandSolder
U1: 74AHCT125; SOIC-14_3.9x8.7mm_P1.27mm; LCSC C2675672

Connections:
+5V: C13.1, C19.1, J2.3, J3.3, J4.3, J5.3, U1.14 (VCC); also elsewhere on the board
GND1: C13.2, C19.2, J2.1, J3.1, J4.1, J5.1, U1.1, U1.4, U1.7 (GND), U1.10, U1.13; also elsewhere on the board
LED1 Signal: U1.2; also elsewhere on the board
LED2 Signal: U1.5; also elsewhere on the board
LED3 Signal: U1.9; also elsewhere on the board
LED4 Signal: U1.12; also elsewhere on the board
unnamed: J2.2, R9.1
unnamed: J3.2, R10.1
unnamed: J4.2, R11.1
unnamed: J5.2, R12.1
unnamed: R9.2, U1.3
unnamed: R10.2, U1.6
unnamed: R11.2, U1.8
unnamed: R12.2, U1.11


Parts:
5V2: TestPoint; TestPoint_Pad_2.0x2.0mm
C1: 220uf; CP_Elec_10x10
C2, C3: 10uf; C_1206_3216Metric_Pad1.33x1.80mm_HandSolder
C4: 0.1uF; C_1210_3225Metric_Pad1.33x2.70mm_HandSolder
C5, C6: 22uF; C_1210_3225Metric_Pad1.33x2.70mm_HandSolder
C7: 0.1uF; C_1206_3216Metric_Pad1.33x1.80mm_HandSolder
D1: SMAJ13A; D_SMA
F1: Polyfuse; Fuse_1812_4532Metric
GND1: TestPoint; TestPoint_Pad_2.0x2.0mm
J1: Conn_01x04_Pin; JST_XH_B2B-XH-AM_1x02_P2.50mm_Vertical
L1: 3.3uH; IND_SPM6530T-3R3M; PARTREV N/A; LCSC C76856
Q1: DMP3013SFV; Diodes_PowerDI3333-8; LCSC C264098
R1, R2: 100k; R_1206_3216Metric_Pad1.30x1.75mm_HandSolder
R5: 54.9k; R_1206_3216Metric_Pad1.30x1.75mm_HandSolder
R6: 10k; R_1206_3216Metric_Pad1.30x1.75mm_HandSolder
U9: TPS565201DDCR; SOT95P280X110-6N; LCSC C327676

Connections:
+5V: 5V2.1, C5.1, C6.1, L1.2, R5.1; also elsewhere on the board
/Power Block/BAT+: F1.2, J1.1
/Power Block/Fuse-Pol: F1.1, Q1.5 (D)
GND1: C1.2, C2.2, C3.2, C5.2, C6.2, C7.2, D1.1 (A1), GND1.1, J1.2, R1.2, R6.2, U9.1 (GND); also elsewhere on the board
Motor Power: C1.1, C2.1, C3.1, C7.1, D1.2 (A2), Q1.1 (S), Q1.2 (S), Q1.3 (S), R2.1, U9.3 (VIN); also elsewhere on the board
unnamed: Q1.4 (G), R1.1
unnamed: R2.2, U9.5 (EN)
unnamed: C4.1, L1.1, U9.2 (SW)
unnamed: C4.2, U9.6 (VBST)
unnamed: R5.2, R6.1, U9.4 (VFB)

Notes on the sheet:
Output Filter
Input Filter
Spike Protection
Reverse Polarity Protection


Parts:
3.3V1, 5V1: LED; LED_1206_3216Metric_Pad1.42x1.75mm_HandSolder
3v3: TestPoint; TestPoint_Pad_2.0x2.0mm
C8, C21: 1uF; C_1206_3216Metric_Pad1.33x1.80mm_HandSolder
C9, C22: 22uF; C_1210_3225Metric_Pad1.33x2.70mm_HandSolder
C20: 0.1uF; C_1206_3216Metric_Pad1.33x1.80mm_HandSolder
D2, D3: SS14; D_SMA
FB1: 600; L_1206_3216Metric
J8: USB_C_Receptacle; USB_C_Receptacle_HCTL_HC-TYPE-C-16P-01A
J9: Conn_01x08_Pin; PinHeader_1x08_P2.54mm_Vertical
J12: Conn_01x08_Pin; PinHeader_1x04_P2.54mm_Vertical
MOTOR1: LED; LED_1206_3216Metric_Pad1.42x1.75mm_HandSolder
R16, R17: 5.1k; R_1206_3216Metric_Pad1.30x1.75mm_HandSolder
R18, R19: 10k; R_1206_3216Metric_Pad1.30x1.75mm_HandSolder
R20, R22: 1.5k; R_1206_3216Metric_Pad1.30x1.75mm_HandSolder
R21, R23, R26: 680; R_1206_3216Metric_Pad1.30x1.75mm_HandSolder
SW1, SW2: SW_Push; SW_SPST_PTS645Sx43SMTR92
SW3: LED; LED_1206_3216Metric_Pad1.42x1.75mm_HandSolder
U4: ESP32-S3-WROOM-1; ESP32-S3-WROOM-2; LCSC C2913198
U5: AP2112K-3.3; SOT-23-5; LCSC C23380830
U6: USBLC6-2SC6; SOT-23-6; LCSC C2827654
USB1: LED; LED_1206_3216Metric_Pad1.42x1.75mm_HandSolder

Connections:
+3V3: 3v3.1, C20.1, C22.1, J12.3, R18.1, R19.1, R21.1, U4.2 (3V3), U5.5 (VOUT); also elsewhere on the board
+5V: FB1.1, J12.4; also elsewhere on the board
/ESP32/A6: J8.A6 (D+), J8.B6 (D+), U6.4 (I/O2)
/ESP32/A7: J8.A7 (D-), J8.B7 (D-), U6.6 (I/O1)
/ESP32/GPIO8: J9.1, U4.12 (IO8)
/ESP32/GPIO9: J9.2, U4.17 (IO9)
/ESP32/GPIO10: J9.3, U4.18 (IO10)
/ESP32/GPIO11: J9.4, U4.19 (IO11)
/ESP32/GPIO12: J9.5, U4.20 (IO12)
/ESP32/GPIO13: J9.6, U4.21 (IO13)
/ESP32/GPIO14: J9.7, U4.22 (IO14)
/ESP32/GPIO21: J9.8, U4.23 (IO21)
/ESP32/SW_LED: R23.1, U4.25 (IO48)
/ESP32/VBUS: D2.2 (A), J8.A4 (VBUS), J8.A9 (VBUS), J8.B4 (VBUS), J8.B9 (VBUS), R22.1, U6.5 (VBUS)
GND1: 3.3V1.1 (K), 5V1.1 (K), C8.2, C9.2, C20.2, C21.2, C22.2, J8.A1 (GND), J8.A12 (GND), J8.B1 (GND), J8.B12 (GND), J12.1, MOTOR1.1 (K), R16.2, R17.2, SW1.1, SW2.2, SW3.1 (K), U4.1 (GND), U4.40 (GND), U4.41 (GND), U5.2 (GND), U6.2 (GND), USB1.1 (K); also elsewhere on the board
I2S_SCK: U4.9 (IO16); also elsewhere on the board
I2S_SD: U4.11 (IO18); also elsewhere on the board
I2S_WS: U4.10 (IO17); also elsewhere on the board
LED1 Signal: U4.4 (IO4); also elsewhere on the board
LED2 Signal: U4.5 (IO5); also elsewhere on the board
LED3 Signal: U4.6 (IO6); also elsewhere on the board
LED4 Signal: U4.7 (IO7); also elsewhere on the board
Motor Power: J12.2; also elsewhere on the board
Motor Signal: R26.1, U4.8 (IO15); also elsewhere on the board
unnamed 26: 3.3V1.2 (A), R21.2; also elsewhere on the board
unnamed 27: 5V1.2 (A), R20.2; also elsewhere on the board
unnamed: C8.1, C9.1, D2.1 (K), D3.1 (K), R20.1, U5.1 (VIN), U5.3 (EN)
unnamed: D3.2 (A), FB1.2
unnamed: MOTOR1.2 (A), R26.2
unnamed 45: R23.2, SW3.2 (A); also elsewhere on the board
unnamed: C21.1, R18.2, SW1.2, U4.3 (EN)
unnamed: R19.2, SW2.1, U4.27 (IO0)
unnamed: U4.14 (USB_D+/IO20), U6.3 (I/O2)
unnamed: U4.13 (USB_D-/IO19), U6.1 (I/O1)
unnamed 57: R22.2, USB1.2 (A); also elsewhere on the board
RS485_DE: U4.35 (MTMS/IO42); also elsewhere on the board
RS485_RX: U4.38 (IO2); also elsewhere on the board
RS485_TX: U4.39 (IO1); also elsewhere on the board

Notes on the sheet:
Expansion Header for future use


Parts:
C8, C21: 1uF
C20: 0.1uF
C22: 22uF
D2: SS14
D4, D5, D6, D7: LED
J8: USB_C_Receptacle
R16, R17: 5.1k
R18, R19: 10k
R20, R22: 1.5k
R21, R23: 680
SW1, SW2: SW_Push
U4: ESP32-S3-WROOM-1; ESP32-S3-WROOM-2
U5: AP2112K-3.3; SOT-23-5
U6: USBLC6-2SC6; SOT-23-6

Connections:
+3V3: C20.1, C22.1, R18.1, R19.1, R21.1, U4.2 (3V3), U5.5 (VOUT); also elsewhere on the board
/ESP32/A6: J8.A6 (D+), J8.B6 (D+), U6.4 (I/O2)
/ESP32/A7: J8.A7 (D-), J8.B7 (D-), U6.6 (I/O1)
/ESP32/GPIO8: U4.12 (IO8); also elsewhere on the board
/ESP32/GPIO9: U4.17 (IO9); also elsewhere on the board
/ESP32/GPIO10: U4.18 (IO10); also elsewhere on the board
/ESP32/GPIO11: U4.19 (IO11); also elsewhere on the board
/ESP32/GPIO12: U4.20 (IO12); also elsewhere on the board
/ESP32/GPIO13: U4.21 (IO13); also elsewhere on the board
/ESP32/GPIO14: U4.22 (IO14); also elsewhere on the board
/ESP32/GPIO21: U4.23 (IO21); also elsewhere on the board
/ESP32/SW_LED: R23.1, U4.25 (IO48)
/ESP32/VBUS: D2.2 (A), J8.A4 (VBUS), J8.A9 (VBUS), J8.B4 (VBUS), J8.B9 (VBUS), R22.1, U6.5 (VBUS)
GND1: C8.2, C20.2, C21.2, C22.2, D4.1 (K), D5.1 (K), D6.1 (K), D7.1 (K), J8.A1 (GND), J8.A12 (GND), J8.B1 (GND), J8.B12 (GND), R16.2, R17.2, SW1.1, SW2.2, U4.1 (GND), U4.40 (GND), U4.41 (GND), U5.2 (GND), U6.2 (GND); also elsewhere on the board
I2S_SCK: U4.9 (IO16); also elsewhere on the board
I2S_SD: U4.11 (IO18); also elsewhere on the board
I2S_WS: U4.10 (IO17); also elsewhere on the board
LED1 Signal: U4.4 (IO4); also elsewhere on the board
LED2 Signal: U4.5 (IO5); also elsewhere on the board
LED3 Signal: U4.6 (IO6); also elsewhere on the board
LED4 Signal: U4.7 (IO7); also elsewhere on the board
Motor Signal: U4.8 (IO15); also elsewhere on the board
unnamed 26: D5.2 (A), R21.2; also elsewhere on the board
unnamed 27: D4.2 (A), R20.2; also elsewhere on the board
unnamed 28: C8.1, D2.1 (K), R20.1, U5.1 (VIN), U5.3 (EN); also elsewhere on the board
unnamed 45: D7.2 (A), R23.2; also elsewhere on the board
unnamed: C21.1, R18.2, SW1.2, U4.3 (EN)
unnamed: R19.2, SW2.1, U4.27 (IO0)
unnamed: U4.14 (USB_D+/IO20), U6.3 (I/O2)
unnamed: U4.13 (USB_D-/IO19), U6.1 (I/O1)
unnamed 57: D6.2 (A), R22.2; also elsewhere on the board
RS485_DE: U4.35 (MTMS/IO42); also elsewhere on the board
RS485_RX: U4.38 (IO2); also elsewhere on the board
RS485_TX: U4.39 (IO1); also elsewhere on the board


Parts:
C14, C15: 10uF 25v; C_1206_3216Metric_Pad1.33x1.80mm_HandSolder
C16: 0.1uF; C_1206_3216Metric_Pad1.33x1.80mm_HandSolder
C17, C18: 22uF; C_1210_3225Metric_Pad1.33x2.70mm_HandSolder
J6, J7: Conn_01x02_Pin; JST_XH_B2B-XH-AM_1x02_P2.50mm_Vertical
L2: 3.3uH; IND_SPM6530T-3R3M; PARTREV N/A; LCSC C76856
R13: 35.7k; R_1206_3216Metric_Pad1.30x1.75mm_HandSolder
R14: 10k; R_1206_3216Metric_Pad1.30x1.75mm_HandSolder
R15: 100k; R_1206_3216Metric_Pad1.30x1.75mm_HandSolder
U3: TPS563201DDCR; TSOT-23-6_HandSoldering; PARTREV December 2015; LCSC C116592

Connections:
GND1: C14.2, C15.2, C17.2, C18.2, J6.1, J7.1, R14.2, R15.2, U3.1 (GND); also elsewhere on the board
Motor Power: C14.1, C15.1, U3.3 (VIN); also elsewhere on the board
Motor Signal: R15.1, U3.5 (EN); also elsewhere on the board
unnamed: C17.1, C18.1, J6.2, J7.2, L2.2, R13.1
unnamed: C16.1, L2.1, U3.2 (SW)
unnamed: C16.2, U3.6 (VBST)
unnamed: R13.2, R14.1, U3.4 (VFB)


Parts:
C23, C24: 0.1uF; C_1206_3216Metric_Pad1.33x1.80mm_HandSolder
C25: 4.7uF; C_1206_3216Metric_Pad1.33x1.80mm_HandSolder
J10: Conn_01x04_Pin; JST_XH_B2B-XH-AM_1x02_P2.50mm_Vertical
J11: Conn_01x08_Pin; JST_XH_B8B-XH-AM_1x08_P2.50mm_Vertical
R24, R29: 100k; R_1206_3216Metric_Pad1.30x1.75mm_HandSolder
R25: 120; R_1206_3216Metric_Pad1.30x1.75mm_HandSolder
R27, R28: 33; R_1206_3216Metric_Pad1.30x1.75mm_HandSolder
U7: THVD1400D; SOIC-8_3.9x4.9mm_P1.27mm; LCSC C3235232
U8: SM712; SOT23-WIDE; LCSC C502564

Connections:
+3V3: C23.1, C24.1, C25.1, J11.1, U7.8 (VCC); also elsewhere on the board
GND1: C23.2, C24.2, C25.2, J11.2, J11.4, J11.6, J11.8, R24.2, R29.2, U7.5 (GND), U8.3; also elsewhere on the board
I2S_SCK: R27.2; also elsewhere on the board
I2S_SD: J11.7, R29.1; also elsewhere on the board
I2S_WS: R28.2; also elsewhere on the board
unnamed: J10.1, R25.2, U7.7 (B), U8.1
unnamed: J10.2, R25.1, U7.6 (A), U8.2
unnamed: J11.3, R27.1
unnamed: J11.5, R28.1
RS485_DE: R24.1, U7.2 (~RE), U7.3 (DE); also elsewhere on the board
RS485_RX: U7.1 (RO); also elsewhere on the board
RS485_TX: U7.4 (DI); also elsewhere on the board

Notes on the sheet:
RS485 Transceiver
INMP441 Module Header
INMP441 Module will be on an 8-10 inch lead from the PCB Connected with CAT5 twisted pair. Ground/Signal for each twisted pair.

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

Board: 4 copper layers, 72.0 x 66.0 mm, 85 parts (0 on the bottom side), 63 nets.

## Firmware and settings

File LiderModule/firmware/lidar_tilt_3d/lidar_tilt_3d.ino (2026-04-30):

#include <Arduino.h>
#include <Wire.h>
#include <SCServo.h>
#include "MPU6050_6Axis_MotionApps20.h"

// Pins: Seeed XIAO ESP32-S3
#define LIDAR_RXD 3
#define LIDAR_TXD 4
#define IMU_SDA 5
#define IMU_SCL 6
#define SERVO_RXD 44
#define SERVO_TXD 43

#define MPU6050_ADDR 0x68
#define SERVO_ID_TILT 1
#define SERVO_CENTER 2048
// +1: normal direction, -1: inverted direction
#define SERVO_DIRECTION -1

#define LIDAR_BAUDRATE 230400
#define SERVO_BAUDRATE 1000000
#define USB_BAUDRATE 921600

#define PROTO_SYNC1 0xFE
#define PROTO_SYNC2 0xEF

#define MSG_IMU_DATA 0x02
#define MSG_SCAN_SLICE 0x04
#define MSG_SCAN_STATUS 0x05
#define CMD_SERVO_ANGLE 0x10
#define CMD_SCAN_START 0x12
#define CMD_SCAN_STOP 0x13

#define TILT_MIN_DEFAULT -45.0f
#define TILT_MAX_DEFAULT 45.0f
#define TILT_STEP_DEFAULT 2.0f
#define TILT_SAFE_LIMIT 50.0f

#define SETTLE_MS_MIN 150
#define SETTLE_MS_MAX 1300
// Production fast-detection profile: capture immediately after the tilt command.
// This intentionally includes points measured while the servo is moving.
#define SCAN_SETTLE_DISABLED 1
#define IMU_READ_MS 10
#define IMU_SEND_MS 50
#define MAX_SCAN_POINTS 720
#define MAX_PROTO_PAYLOAD 4096
#define CAPTURE_TIMEOUT_MS 110
#define CAPTURE_MIN_POINTS 25
#define SWEEP_PREPARE_MS 120
#define SWEEP_FINALIZE_MS 500
#define SWEEP_LIDAR_REV_HZ 6.0f
#define SWEEP_SPEED_MIN_DPS 4.0f
#define SWEEP_SPEED_MAX_DPS 80.0f
// Human-readable USB debug mode.
// 1: Print IMU + servo ReadPos as text and suppress binary TX frames.
// 0: Normal binary protocol behavior.
#define USB_TEXT_DEBUG_MODE 0

HardwareSerial LidarSerial(1);
SMS_STS servo;
MPU6050 mpu(MPU6050_ADDR, &Wire);

struct LidarPoint {
  uint16_t angle_x100;
  uint16_t dist_mm;
  uint8_t quality;
};

static LidarPoint scanPoints[MAX_SCAN_POINTS];
static uint16_t scanCount = 0;
static volatile bool scanReady = false;
static bool hasSentSliceInCurrentScan = false;

static float imuPitch = 0.0f;
static float imuRoll = 0.0f;
static float imuYaw = 0.0f;
static uint32_t lastImuReadMs = 0;
static uint32_t lastImuSendMs = 0;
static uint8_t servoTxId = SERVO_ID_TILT;
static int8_t servoReadId = -1;
static uint32_t lastServoDebugMs = 0;
static uint32_t lastServoProbeMs = 0;
static bool dmpReady = false;
static uint16_t dmpPacketSize = 0;
static uint8_t dmpFifoBuffer[64];
static Quaternion dmpQ;
static VectorFloat dmpGravity;
static float dmpYpr[3];

enum Scan3DState {
  S3D_IDLE,
  S3D_PREPARE,
  S3D_SWEEPING,
  S3D_FINALIZING,
  S3D_COMPLETE
};

static Scan3DState scanState = S3D_IDLE;
static float tiltMin = TILT_MIN_DEFAULT;
static float tiltMax = TILT_MAX_DEFAULT;
static float tiltStep = TILT_STEP_DEFAULT;
static float currentTilt = 0.0f;
static uint16_t stepIndex = 0;
static uint16_t totalSteps = 0;
static uint32_t stateStartedMs = 0;
static uint32_t settleMsCurrent = SETTLE_MS_MIN;
static float captureTiltStart = 0.0f;
static float captureTiltEnd = 0.0f;
static float sweepSpeedDps = 0.0f;
static int8_t sweepDirection = 1;
static uint32_t lastSweepUpdateMs = 0;
static uint16_t slicesSent = 0;

static uint8_t rxFrame[128];
static uint16_t rxIndex = 0;
static uint16_t rxLen = 0;
static uint8_t rxType = 0;
static uint8_t rxState = 0;

static uint8_t lidarBuf[2300];
static uint16_t lidarIndex = 0;
static uint16_t lidarExpected = 0;
static uint8_t lidarState = 0;
static bool lidarMotorOn = false;
static int8_t probeServoId();

static uint8_t checksum(uint8_t type, uint16_t len, const uint8_t *payload) {
  uint8_t cs = type ^ (uint8_t)(len & 0xFF) ^ (uint8_t)(len >> 8);
  for (uint16_t i = 0; i < len; i++) {
    cs ^= payload[i];
  }
  return cs;
}

static void writeU16(uint8_t *p, uint16_t v) {
  p[0] = (uint8_t)(v & 0xFF);
  p[1] = (uint8_t)(v >> 8);
}

static void writeF32(uint8_t *p, float v) {
  memcpy(p, &v, sizeof(float));
}

static float readF32(const uint8_t *p) {
  float v;
  memcpy(&v, p, sizeof(float));
  return v;
}

static void sendFrame(uint8_t type, const uint8_t *payload, uint16_t len) {
#if USB_TEXT_DEBUG_MODE
  (void)type;
  (void)payload;
  (void)len;
  return;
#else
  Serial.write(PROTO_SYNC1);
  Serial.write(PROTO_SYNC2);
  Serial.write(type);
  Serial.write((uint8_t)(len & 0xFF));
  Serial.write((uint8_t)(len >> 8));
  if (len > 0 && payload != nullptr) {
    Serial.write(payload, len);
  }
  Serial.write(checksum(type, len, payload));
#endif
}

static void sendStatus(uint8_t state, uint16_t step, uint16_t total) {
  uint8_t payload[5];
  payload[0] = state;
  writeU16(payload + 1, step);
  writeU16(payload + 3, total);
  sendFrame(MSG_SCAN_STATUS, payload, sizeof(payload));
}

static int angleToServoPos(float angleDeg) {
  float limited = constrain(angleDeg, -TILT_SAFE_LIMIT, TILT_SAFE_LIMIT);
  int pos = SERVO_CENTER + (int)(SERVO_DIRECTION * limited * 4096.0f / 360.0f);
  return constrain(pos, 0, 4095);
}

static void setTiltAngle(float angleDeg) {
  currentTilt = constrain(angleDeg, -TILT_SAFE_LIMIT, TILT_SAFE_LIMIT);
  int pos = angleToServoPos(currentTilt);
  servo.WritePosEx(servoTxId, pos, 1800, 50);
}

static float servoPosToAngle(int pos) {
  return ((float)(pos - SERVO_CENTER)) * 360.0f / (4096.0f * (float)SERVO_DIRECTION);
}

static bool readServoTilt(float *angleDegOut) {
  uint32_t nowMs = millis();
  if (servoReadId < 0 && (nowMs - lastServoProbeMs >= 2000)) {
    lastServoProbeMs = nowMs;
    servoReadId = probeServoId();
  }

  if (servoReadId < 0) {
    return false;
  }

  int pos = servo.ReadPos(servoReadId);
  if (pos < 0) {
    servoReadId = -1;
    return false;
  }

  *angleDegOut = constrain(servoPosToAngle(pos), -TILT_SAFE_LIMIT, TILT_SAFE_LIMIT);
  return true;
}

static void initServo() {
  delay(100);
  // Prefer the expected ID first.
  if (servo.Ping(SERVO_ID_TILT) != -1) {
    servoTxId = SERVO_ID_TILT;
    servoReadId = SERVO_ID_TILT;
    servo.EnableTorque(servoTxId, 1);
    return;
  }

  // Try to detect a servo ID on a typical small range.
  for (uint8_t id = 0; id <= 20; id++) {
    if (servo.Ping(id) != -1) {
      servoTxId = id;
      servoReadId = id;
      servo.EnableTorque(servoTxId, 1);
      return;
    }
    delay(10);
  }

  // Fallback: broadcast command works even when ID is unknown.
  servoTxId = 0xFE;
  servoReadId = -1;
}

static int8_t probeServoId() {
  if (servoTxId != 0xFE && servo.Ping(servoTxId) != -1) {
    return (int8_t)servoTxId;
  }
  for (uint8_t id = 0; id <= 20; id++) {
    if (servo.Ping(id) != -1) {
      return (int8_t)id;
    }
    delay(2);
  }
  return (int8_t)-1;
}

static void debugServoImuStatus(uint32_t nowMs) {
#if USB_TEXT_DEBUG_MODE
  if (nowMs - lastServoDebugMs < 250) {
    return;
  }
  lastServoDebugMs = nowMs;

  if (servoReadId < 0 && (nowMs - lastServoProbeMs >= 2000)) {
    lastServoProbeMs = nowMs;
    servoReadId = probeServoId();
  }

  int pos = -1;
  if (servoReadId >= 0) {
    pos = servo.ReadPos(servoReadId);
    if (pos < 0) {
      servoReadId = -1;
    }
  }

  Serial.print("[dbg] tx_id=");
  Serial.print((int)servoTxId);
  Serial.print(" read_id=");
  Serial.print((int)servoReadId);
  Serial.print(" read_pos=");
  Serial.print(pos);
  Serial.print(" tilt=");
  Serial.print(currentTilt, 2);
  Serial.print(" imu_pitch=");
  Serial.print(imuPitch, 2);
  Serial.print(" imu_roll=");
  Serial.print(imuRoll, 2);
  Serial.print(" imu_yaw=");
  Serial.println(imuYaw, 2);
#else
  (void)nowMs;
#endif
}

static void initImu() {
  Wire.begin(IMU_SDA, IMU_SCL);
  Wire.setClock(400000);
  delay(100);

  mpu.initialize();
  uint8_t devStatus = mpu.dmpInitialize();
  if (devStatus == 0) {
    mpu.setDMPEnabled(true);
    dmpPacketSize = mpu.dmpGetFIFOPacketSize();
    dmpReady = true;
  } else {
    dmpReady = false;
  }
}

static void updateImu() {
  if (!dmpReady) {
    return;
  }

  if (!mpu.dmpGetCurrentFIFOPacket(dmpFifoBuffer)) {
    return;
  }
  mpu.dmpGetQuaternion(&dmpQ, dmpFifoBuffer);
  mpu.dmpGetGravity(&dmpGravity, &dmpQ);
  mpu.dmpGetYawPitchRoll(dmpYpr, &dmpQ, &dmpGravity);

  imuYaw = dmpYpr[0] * 180.0f / PI;
  imuPitch = dmpYpr[1] * 180.0f / PI;
  imuRoll = dmpYpr[2] * 180.0f / PI;
}

static void sendImu() {
  uint8_t payload[12];
  writeF32(payload + 0, imuPitch);
  writeF32(payload + 4, imuRoll);
  writeF32(payload + 8, imuYaw);
  sendFrame(MSG_IMU_DATA, payload, sizeof(payload));
}

static void resetLidarScan() {
  scanCount = 0;
  scanReady = false;
}

static float rawAngleDeg(uint16_t raw) {
  return (float)(raw >> 1) / 64.0f;
}

static void processLidarPacket(const uint8_t *pkt, uint16_t len) {
  if (scanReady) {
    // Drop incoming packets until host side consumes the completed slice.
    return;
  }
  if (len < 10) {
    return;
  }
  uint8_t ct = pkt[2];
  uint8_t lsn = pkt[3];
  if (lsn == 0 || len < (uint16_t)(10 + lsn * 3)) {
    return;
  }

  bool newScan = (ct & 0x01) != 0;
  if (newScan && scanCount > 0) {
    captureTiltEnd = currentTilt;
    if (!readServoTilt(&captureTiltEnd)) {
      captureTiltEnd = currentTilt;
    }
    scanReady = true;
    return;
  }

  float start = rawAngleDeg((uint16_t)pkt[4] | ((uint16_t)pkt[5] << 8));
  float end = rawAngleDeg((uint16_t)pkt[6] | ((uint16_t)pkt[7] << 8));
  float span = end - start;
  if (span < 0.0f) {
    span += 360.0f;
  }

  for (uint8_t i = 0; i < lsn && scanCount < MAX_SCAN_POINTS; i++) {
    if (scanCount == 0 && i == 0) {
      captureTiltStart = currentTilt;
      if (!readServoTilt(&captureTiltStart)) {
        captureTiltStart = currentTilt;
      }
      captureTiltEnd = captureTiltStart;
    }
    const uint8_t *s = pkt + 10 + i * 3;
    float angle = start + (lsn > 1 ? span * i / (float)(lsn - 1) : 0.0f);
    while (angle >= 360.0f) {
      angle -= 360.0f;
    }
    scanPoints[scanCount].angle_x100 = (uint16_t)(angle * 100.0f + 0.5f);
    scanPoints[scanCount].dist_mm = (uint16_t)s[1] | ((uint16_t)s[2] << 8);
    scanPoints[scanCount].quality = s[0];
    scanCount++;
  }

  if (scanCount > 0) {
    captureTiltEnd = currentTilt;
    if (!readServoTilt(&captureTiltEnd)) {
      captureTiltEnd = currentTilt;
    }
  }
}

static void lidarStartMotor() {
  if (lidarMotorOn) {
    return;
  }
  const uint8_t cmd[] = {0xA5, 0x60};
  LidarSerial.write(cmd, sizeof(cmd));
  lidarMotorOn = true;
}

static void lidarStopMotor() {
  if (!lidarMotorOn) {
    return;
  }
  const uint8_t cmd[] = {0xA5, 0x65};
  LidarSerial.write(cmd, sizeof(cmd));
  lidarMotorOn = false;
}

static void pollLidar() {
  // Avoid starving other tasks when LiDAR stream is continuous.
  int budget = 512;
  while (budget-- > 0 && LidarSerial.available()) {
    uint8_t b = (uint8_t)LidarSerial.read();
    switch (lidarState) {
      case 0:
        if (b == 0xAA) {
          lidarBuf[0] = b;
          lidarIndex = 1;
          lidarState = 1;
        }
        break;
      case 1:
        if (b == 0x55) {
          lidarBuf[lidarIndex++] = b;
          lidarState = 2;
        } else {
          lidarState = 0;
        }
        break;
      case 2:
        lidarBuf[lidarIndex++] = b;
        if (lidarIndex == 4) {
          lidarExpected = 10 + (uint16_t)lidarBuf[3] * 3;
          if (lidarExpected > sizeof(lidarBuf)) {
            lidarState = 0;
          }
        }
        if (lidarIndex >= 4 && lidarIndex >= lidarExpected) {
          processLidarPacket(lidarBuf, lidarIndex);
          lidarState = 0;
        }
        break;
    }
  }
}

static void sendScanSlice() {
  uint16_t count = scanCount;
  uint16_t len = 22 + count * 5;
  if (len > MAX_PROTO_PAYLOAD) {
    count = (MAX_PROTO_PAYLOAD - 22) / 5;
    len = 22 + count * 5;
  }

  static uint8_t payload[MAX_PROTO_PAYLOAD];
  writeF32(payload + 0, currentTilt);
  writeF32(payload + 4, captureTiltStart);
  writeF32(payload + 8, captureTiltEnd);
  writeF32(payload + 12, imuPitch);
  writeF32(payload + 16, imuRoll);
  writeU16(payload + 20, count);
  for (uint16_t i = 0; i < count; i++) {
    uint8_t *p = payload + 22 + i * 5;
    writeU16(p + 0, scanPoints[i].angle_x100);
    writeU16(p + 2, scanPoints[i].dist_mm);
    p[4] = scanPoints[i].quality;
  }
  sendFrame(MSG_SCAN_SLICE, payload, len);
}

static uint32_t computeSettleMs(float deltaDeg) {
#if SCAN_SETTLE_DISABLED
  (void)deltaDeg;
  return 0;
#else
  float a = fabsf(deltaDeg);
  // Faster profile:
  // keep ~1.25s class at 45deg while reducing small-step overhead.
  uint32_t ms = (uint32_t)(110.0f + 25.0f * a + 0.5f);
  if (ms < SETTLE_MS_MIN) {
    ms = SETTLE_MS_MIN;
  }
  if (ms > SETTLE_MS_MAX) {
    ms = SETTLE_MS_MAX;
  }
  return ms;
#endif
}

static uint16_t computeTotalSteps(float minA, float maxA, float stepA) {
  if (stepA <= 0.0f || maxA < minA) {
    return 0;
  }
  return (uint16_t)(floorf((maxA - minA) / stepA + 0.5f) + 1);
}

static void updateSweepCommand() {
  uint32_t nowMs = millis();
  uint32_t dtMs = nowMs - lastSweepUpdateMs;
  if (dtMs == 0) {
    return;
  }
  lastSweepUpdateMs = nowMs;

  float dt = (float)dtMs / 1000.0f;
  float next = currentTilt + (float)sweepDirection * sweepSpeedDps * dt;
  if (next > tiltMax) {
    next = tiltMax;
  }
  if (next < tiltMin) {
    next = tiltMin;
  }
  currentTilt = next;
  setTiltAngle(currentTilt);
}

static void startScan(float minA, float maxA, float stepA) {
  tiltMin = constrain(minA, -TILT_SAFE_LIMIT, TILT_SAFE_LIMIT);
  tiltMax = constrain(maxA, -TILT_SAFE_LIMIT, TILT_SAFE_LIMIT);
  // Single-angle requests are fragile in continuous-sweep mode.
  // Expand to a narrow sweep so at least one full LiDAR revolution can be captured.
  if (fabsf(tiltMax - tiltMin) < 0.2f) {
    float center = 0.5f * (tiltMin + tiltMax);
    tiltMin = constrain(center - 2.0f, -TILT_SAFE_LIMIT, TILT_SAFE_LIMIT);
    tiltMax = constrain(center + 2.0f, -TILT_SAFE_LIMIT, TILT_SAFE_LIMIT);
  }
  tiltStep = stepA > 0.0f ? stepA : TILT_STEP_DEFAULT;
  if (tiltMax < tiltMin) {
    float t = tiltMin;
    tiltMin = tiltMax;
    tiltMax = t;
  }
  totalSteps = computeTotalSteps(tiltMin, tiltMax, tiltStep);
  if (totalSteps == 0) {
    return;
  }
  float spacing = stepA > 0.0f ? stepA : TILT_STEP_DEFAULT;
  sweepSpeedDps = constrain(fabsf(spacing) * SWEEP_LIDAR_REV_HZ, SWEEP_SPEED_MIN_DPS, SWEEP_SPEED_MAX_DPS);
  lidarStartMotor();
  stepIndex = 0;
  slicesSent = 0;
  sweepDirection = 1;
  currentTilt = tiltMin;
  setTiltAngle(currentTilt);
  resetLidarScan();
  hasSentSliceInCurrentScan = false;
  captureTiltStart = currentTilt;
  captureTiltEnd = currentTilt;
  scanState = S3D_PREPARE;
  stateStartedMs = millis();
  lastSweepUpdateMs = stateStartedMs;
  sendStatus(0, stepIndex, totalSteps);
}

static void stopScan() {
  scanState = S3D_IDLE;
  lidarStopMotor();
  resetLidarScan();
  setTiltAngle(0.0f);
  if (hasSentSliceInCurrentScan) {
    sendStatus(2, stepIndex, totalSteps);
  }
}

static void updateScanState() {
  switch (scanState) {
    case S3D_IDLE:
      break;
    case S3D_PREPARE:
      if (millis() - stateStartedMs >= SWEEP_PREPARE_MS) {
        resetLidarScan();
        lastSweepUpdateMs = millis();
        scanState = S3D_SWEEPING;
      }
      break;
    case S3D_SWEEPING:
      updateSweepCommand();
      if (scanReady) {
        if (scanCount >= CAPTURE_MIN_POINTS) {
          sendScanSlice();
          hasSentSliceInCurrentScan = true;
          slicesSent++;
        }
        resetLidarScan();
        uint16_t progress = slicesSent;
        if (progress > totalSteps) {
          progress = totalSteps;
        }
        sendStatus(1, progress, totalSteps);
      }
      // Capture both directions:
      //  1) up-sweep: tiltMin -> tiltMax
      //  2) down-sweep: tiltMax -> tiltMin
      if (sweepDirection > 0 && currentTilt >= (tiltMax - 0.01f)) {
        sweepDirection = -1;
      } else if (sweepDirection < 0 && currentTilt <= (tiltMin + 0.01f)) {
        stateStartedMs = millis();
        scanState = S3D_FINALIZING;
      }
      break;
    case S3D_FINALIZING:
      setTiltAngle(tiltMin);
      if (scanReady) {
        if (scanCount >= CAPTURE_MIN_POINTS) {
          sendScanSlice();
          hasSentSliceInCurrentScan = true;
          slicesSent++;
        }
        resetLidarScan();
        uint16_t progress = slicesSent;
        if (progress > totalSteps) {
          progress = totalSteps;
        }
        sendStatus(1, progress, totalSteps);
      }
      if (millis() - stateStartedMs >= SWEEP_FINALIZE_MS) {
        scanState = S3D_COMPLETE;
      }
      break;
    case S3D_COMPLETE:
      setTiltAngle(0.0f);
      // Keep LiDAR motor spinning across scan cycles.
      // Motor stop is handled only by explicit CMD_SCAN_STOP.
      if (hasSentSliceInCurrentScan) {
        sendStatus(2, totalSteps, totalSteps);
      }
      scanState = S3D_IDLE;
      break;
  }
}

static void handleCommand(uint8_t type, const uint8_t *payload, uint16_t len) {
  if (type == CMD_SERVO_ANGLE && len >= 4) {
    setTiltAngle(readF32(payload));
  } else if (type == CMD_SCAN_START) {
    if (len >= 12) {
      startScan(readF32(payload), readF32(payload + 4), readF32(payload + 8));
    } else {
      startScan(TILT_MIN_DEFAULT, TILT_MAX_DEFAULT, TILT_STEP_DEFAULT);
    }
  } else if (type == CMD_SCAN_STOP) {
    stopScan();
  }
}

static void pollUsbCommands() {
  while (Serial.available()) {
    uint8_t b = (uint8_t)Serial.read();
    switch (rxState) {
      case 0:
        rxState = (b == PROTO_SYNC1) ? 1 : 0;
        break;
      case 1:
        rxState = (b == PROTO_SYNC2) ? 2 : 0;
        break;
      case 2:
        rxType = b;
        rxState = 3;
        break;
      case 3:
        rxLen = b;
        rxState = 4;
        break;
      case 4:
        rxLen |= ((uint16_t)b << 8);
        rxIndex = 0;
        if (rxLen > sizeof(rxFrame)) {
          rxState = 0;
        } else {
          rxState = rxLen == 0 ? 6 : 5;
        }
        break;
      case 5:
        rxFrame[rxIndex++] = b;
        if (rxIndex >= rxLen) {
          rxState = 6;
        }
        break;
      case 6: {
        uint8_t cs = checksum(rxType, rxLen, rxFrame);
        if (cs == b) {
          handleCommand(rxType, rxFrame, rxLen);
        }
        rxState = 0;
        break;
      }
    }
  }
}

void setup() {
  Serial.begin(USB_BAUDRATE);
  Serial0.begin(SERVO_BAUDRATE, SERIAL_8N1, SERVO_RXD, SERVO_TXD);
  LidarSerial.begin(LIDAR_BAUDRATE, SERIAL_8N1, LIDAR_RXD, LIDAR_TXD);
  servo.pSerial = &Serial0;
  initServo();
  // If no servo response, retry once with swapped UART pins.
  if (servoReadId < 0) {
    Serial0.end();
    delay(50);
    Serial0.begin(SERVO_BAUDRATE, SERIAL_8N1, SERVO_TXD, SERVO_RXD);
    delay(50);
    initServo();
  }
#if USB_TEXT_DEBUG_MODE
  Serial.println("[dbg] USB_TEXT_DEBUG_MODE=1 (binary TX disabled)");
  Serial.print("[dbg] init tx_id=");
  Serial.println((int)servoTxId);
#endif
  initImu();

  lidarStopMotor();
  setTiltAngle(0.0f);
}

void loop() {
  pollLidar();
  pollUsbCommands();

  uint32_t now = millis();
  if (now - lastImuReadMs >= IMU_READ_MS) {
    lastImuReadMs = now;
    updateImu();
  }
  if (now - lastImuSendMs >= IMU_SEND_MS) {
    lastImuSendMs = now;
    sendImu();
  }
  debugServoImuStatus(now);
  updateScanState();
}

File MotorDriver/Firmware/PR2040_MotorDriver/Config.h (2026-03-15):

#pragma once

// =============================================================================
// PR2040_DC_MOTOR_DRIVER REV1.5.0 - Pin Configuration
// MCU: RP2040
// =============================================================================

// --- Motor Control (TB67H451 H-bridge x4) ------------------------------------
// Direction/PWM via IN1, IN2
constexpr uint8_t MOTOR1_IN1 = 8;
constexpr uint8_t MOTOR1_IN2 = 9;
constexpr uint8_t MOTOR2_IN1 = 10;
constexpr uint8_t MOTOR2_IN2 = 11;
constexpr uint8_t MOTOR3_IN1 = 14;
constexpr uint8_t MOTOR3_IN2 = 15;
constexpr uint8_t MOTOR4_IN1 = 16;
constexpr uint8_t MOTOR4_IN2 = 17;

constexpr uint8_t MOTOR_IN1[4] = { MOTOR1_IN1, MOTOR2_IN1, MOTOR3_IN1, MOTOR4_IN1 };
constexpr uint8_t MOTOR_IN2[4] = { MOTOR1_IN2, MOTOR2_IN2, MOTOR3_IN2, MOTOR4_IN2 };

// --- Encoder Input (Quadrature x4) -------------------------------------------
constexpr uint8_t ENC1_A = 18;
constexpr uint8_t ENC1_B = 19;
constexpr uint8_t ENC2_A = 20;
constexpr uint8_t ENC2_B = 21;
constexpr uint8_t ENC3_A = 22;
constexpr uint8_t ENC3_B = 23;
constexpr uint8_t ENC4_A = 24;
constexpr uint8_t ENC4_B = 25;

constexpr uint8_t ENC_A[4] = { ENC1_A, ENC2_A, ENC3_A, ENC4_A };
constexpr uint8_t ENC_B[4] = { ENC1_B, ENC2_B, ENC3_B, ENC4_B };

// --- Status LEDs -------------------------------------------------------------
constexpr uint8_t LED_RED_PIN    = 29;  // RED    LED (GPIO29)
constexpr uint8_t LED_GREEN_PIN  = 28;  // GREEN  LED (GPIO28)
constexpr uint8_t LED_YELLOW_PIN = 27;  // YELLOW LED (GPIO27) — heartbeat

// --- Internal ADC (RP2040 ADC0-3) --------------------------------------------
// Connected to INA21x current sense amplifier outputs (via LPF)
// Note: GPIO27-29 are shared with LEDs above; ADC reads will be affected
// while LEDs are driven HIGH.
constexpr uint8_t ADC_CURRENT_CH[4] = { 26, 27, 28, 29 };  // ADC0-3

// --- I2C1: Controller communication (slave) ----------------------------------
// GPIO2 = SDA, GPIO3 = SCL  (I2C1 peripheral)
constexpr uint8_t I2C1_SDA_PIN    = 2;
constexpr uint8_t I2C1_SCL_PIN    = 3;
constexpr uint8_t I2C_SLAVE_ADDR  = 0x60;  // 7-bit slave address

// I2C Register map
// Write registers (controller writes to this board):
//   REG_MOTOR_ALL      [8 B]  int16 x4  motor duties -1000..+1000 (little-endian)
//   REG_MOTOR_SINGLE   [3 B]  uint8 index(0-3) + int16 duty
//   REG_STOP_ALL       [0 B]  coast all motors
//   REG_BRAKE_ALL      [0 B]  active brake all motors
//   REG_RESET_ENC      [0 B]  reset all encoder counts
//   REG_SET_MODE_ALL   [4 B]  uint8 x4  control mode (0=DIRECT,1=VEL,2=POS)
//   REG_SET_MODE_SINGLE[2 B]  uint8 index + uint8 mode
//   REG_SET_VEL_ALL    [16 B] float x4  velocity targets (counts/sec)
//   REG_SET_VEL_SINGLE [5 B]  uint8 index + float target
//   REG_SET_POS_ALL    [16 B] int32 x4  position targets (counts)
//   REG_SET_POS_SINGLE [5 B]  uint8 index + int32 target
//   REG_SET_VEL_PID    [13 B] uint8 index + float kp, ki, kd
//   REG_SET_POS_GAINS  [9 B]  uint8 index + float posKp, maxVelCps
//
// Read registers (controller reads from this board):
//   REG_ENC0..3      [4 B each]  int32 encoder count (little-endian)
//   REG_VEL0..3      [4 B each]  int32 velocity (counts/sec, little-endian)
//   REG_ADC0..3      [2 B each]  int16 ADC raw 0..4095 (little-endian)
//   REG_STATUS       [44 B]  enc(int32x4)+vel(int32x4)+adc(int16x4)+timestamp(uint32)
//   REG_DEVICE_ID    [2 B]   0x20, 0x40

constexpr uint8_t REG_MOTOR_ALL       = 0x01;
constexpr uint8_t REG_MOTOR_SINGLE    = 0x02;
constexpr uint8_t REG_STOP_ALL        = 0x03;
constexpr uint8_t REG_BRAKE_ALL       = 0x04;
constexpr uint8_t REG_RESET_ENC       = 0x05;
constexpr uint8_t REG_SET_MODE_ALL    = 0x06;
constexpr uint8_t REG_SET_MODE_SINGLE = 0x07;
constexpr uint8_t REG_SET_VEL_ALL     = 0x08;
constexpr uint8_t REG_SET_VEL_SINGLE  = 0x09;
constexpr uint8_t REG_SET_POS_ALL     = 0x0A;
constexpr uint8_t REG_SET_POS_SINGLE  = 0x0B;
constexpr uint8_t REG_SET_VEL_PID     = 0x0C;
constexpr uint8_t REG_SET_POS_GAINS   = 0x0D;
constexpr uint8_t REG_ENC0            = 0x10;  // 0x10-0x13
constexpr uint8_t REG_VEL0            = 0x14;  // 0x14-0x17
constexpr uint8_t REG_ADC0            = 0x20;  // 0x20-0x23
constexpr uint8_t REG_STATUS          = 0x30;
constexpr uint8_t REG_BOARD_TEMP      = 0x60;  // Board temperature (float, °C)
constexpr uint8_t REG_DEVICE_ID       = 0xFF;

// --- IMU: MPU-6881 (I2C0) ----------------------------------------------------
constexpr uint8_t IMU_INT_PIN  = 0;
constexpr uint8_t I2C0_SDA_PIN = 12;
constexpr uint8_t I2C0_SCL_PIN = 13;
constexpr uint8_t MPU6881_I2C_ADDR = 0x68;
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

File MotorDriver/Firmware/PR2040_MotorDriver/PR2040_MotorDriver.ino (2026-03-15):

/**
 * PR2040_DC_MOTOR_DRIVER Firmware
 *
 * Hardware : PR2040_BASESYSTEM REV1.5.0  (N.W Works)
 * MCU      : RP2040
 * Arduino  : arduino-pico (Earle Philhower)
 *            https://github.com/earlephilhower/arduino-pico
 *
 * ---- Pin Assignment (from schematic) ----------------------------------------
 *
 * Motor (TB67H451 H-bridge x4)
 *   Motor1  IN1=GPIO8   IN2=GPIO9
 *   Motor2  IN1=GPIO10  IN2=GPIO11
 *   Motor3  IN1=GPIO14  IN2=GPIO15
 *   Motor4  IN1=GPIO16  IN2=GPIO17
 *
 * Encoder (Quadrature x4)
 *   Enc1  A=GPIO18  B=GPIO19
 *   Enc2  A=GPIO20  B=GPIO21
 *   Enc3  A=GPIO22  B=GPIO23
 *   Enc4  A=GPIO24  B=GPIO25
 *
 * ADC Internal (RP2040, current sensing via INA21x + LPF)
 *   CH0=GPIO26  CH1=GPIO27  CH2=GPIO28  CH3=GPIO29
 *
 * Controller I2C (I2C1 slave, addr=0x60)
 *   SDA=GPIO2  SCL=GPIO3
 *
 * IMU MPU-6881 (I2C0)
 *   INT=GPIO0  SDA=GPIO12  SCL=GPIO13
 *
 * External ADC MCP3208/MAX11125 (SPI0)
 *   MISO=GPIO4  CS=GPIO5  SCK=GPIO6  MOSI=GPIO7
 *
 * ---- Control Modes ----------------------------------------------------------
 *
 * Each wheel has three control modes:
 *   0  DIRECT   : duty set directly, no feedback (-1000..+1000)
 *   1  VELOCITY : velocity PID, target in counts/sec
 *   2  POSITION : cascade control (outer P -> velocity PI -> duty)
 *
 * Default PID gains (velocity inner loop):
 *   Kp=1.0  Ki=0.05  Kd=0.0  output: -1000..+1000
 * Default position outer loop:
 *   posKp=0.5  maxVelCps=2000 counts/sec
 *
 * ---- I2C Slave Register Map (Wire1, addr=I2C_SLAVE_ADDR) -------------------
 *
 * Write (controller -> board):
 *   0x01 REG_MOTOR_ALL      [ 8 B]  int16 x4  duty -1000..+1000 (little-endian)
 *   0x02 REG_MOTOR_SINGLE   [ 3 B]  uint8 index(0-3) + int16 duty
 *   0x03 REG_STOP_ALL       [ 0 B]  coast all motors
 *   0x04 REG_BRAKE_ALL      [ 0 B]  active brake all motors
 *   0x05 REG_RESET_ENC      [ 0 B]  reset encoder counts
 *   0x06 REG_SET_MODE_ALL   [ 4 B]  uint8 x4  (0=DIRECT,1=VEL,2=POS)
 *   0x07 REG_SET_MODE_SINGLE[ 2 B]  uint8 index + uint8 mode
 *   0x08 REG_SET_VEL_ALL    [16 B]  float x4  velocity targets (cps)
 *   0x09 REG_SET_VEL_SINGLE [ 5 B]  uint8 index + float target
 *   0x0A REG_SET_POS_ALL    [16 B]  int32 x4  position targets (counts)
 *   0x0B REG_SET_POS_SINGLE [ 5 B]  uint8 index + int32 target
 *   0x0C REG_SET_VEL_PID    [13 B]  uint8 index + float kp, ki, kd
 *   0x0D REG_SET_POS_GAINS  [ 9 B]  uint8 index + float posKp, maxVelCps
 *
 * Read (controller reads after writing register address):
 *   0x10 REG_ENC0  [4 B] int32  encoder 0 count
 *   0x11 REG_ENC1  [4 B] int32  encoder 1 count
 *   0x12 REG_ENC2  [4 B] int32  encoder 2 count
 *   0x13 REG_ENC3  [4 B] int32  encoder 3 count
 *   0x14 REG_VEL0  [4 B] int32  wheel 0 velocity (counts/sec)
 *   0x15 REG_VEL1  [4 B] int32  wheel 1 velocity
 *   0x16 REG_VEL2  [4 B] int32  wheel 2 velocity
 *   0x17 REG_VEL3  [4 B] int32  wheel 3 velocity
 *   0x20 REG_ADC0  [2 B] int16  ADC ch0 raw (0..4095)
 *   0x21 REG_ADC1  [2 B] int16  ADC ch1 raw
 *   0x22 REG_ADC2  [2 B] int16  ADC ch2 raw
 *   0x23 REG_ADC3  [2 B] int16  ADC ch3 raw
 *   0x30 REG_STATUS [44 B] enc(int32x4)+vel(int32x4)+adc(int16x4)+ts(uint32)
 *   0xFF REG_DEVICE_ID [2 B] 0x20 0x40
 *
 * ---- USB Serial Protocol ----------------------------------------------------
 *
 * USB CDC Serial (115200 baud)
 * Packet format: [0xAA][CMD][LEN][DATA x LEN][CHECKSUM]
 * CHECKSUM = XOR(CMD, LEN, DATA[0..LEN-1])
 *
 * Commands (Host -> Board):
 *   0x01  CMD_SET_MOTORS       data: int16 x4 (duty -1000..+1000, little-endian)
 *   0x02  CMD_STOP_ALL         data: none (coast)
 *   0x03  CMD_BRAKE_ALL        data: none (active brake)
 *   0x04  CMD_SET_MOTOR_SINGLE data: uint8 index(0-3), int16 duty
 *   0x10  CMD_REQUEST_STATUS   data: none (triggers one status packet)
 *   0x11  CMD_RESET_ENCODERS   data: none
 *   0x12  CMD_REQUEST_EXT_ADC  data: none → RESP_EXT_ADC int16 x8 (16 B)
 *   0x20  CMD_SET_MODE_ALL     data: uint8 x4  (0=DIRECT,1=VEL,2=POS)
 *   0x21  CMD_SET_MODE_SINGLE  data: uint8 index, uint8 mode
 *   0x22  CMD_SET_VEL_ALL      data: float x4  velocity targets (cps)
 *   0x23  CMD_SET_VEL_SINGLE   data: uint8 index, float target
 *   0x24  CMD_SET_POS_ALL      data: int32 x4  position targets (counts)
 *   0x25  CMD_SET_POS_SINGLE   data: uint8 index, int32 target
 *   0x26  CMD_SET_VEL_PID      data: uint8 index, float kp, ki, kd
 *   0x27  CMD_SET_POS_GAINS    data: uint8 index, float posKp, maxVelCps
 *
 * Responses (Board -> Host):
 *   0x80  RESP_ACK     data: [cmd]
 *   0x81  RESP_NAK     data: [cmd]
 *   0x91  RESP_STATUS  [44 B] enc(int32x4)+vel(int32x4)+adc(int16x4)+ts(uint32)
 *   0x92  RESP_EXT_ADC [16 B] int16 x8 MCP3208 ch0..7
 *
 * Status is also sent automatically at STATUS_INTERVAL_MS (10 ms = 100 Hz).
 */

#include <Wire.h>
#include <SPI.h>
#include <EEPROM.h>
#include <MadgwickAHRS.h>
#include "Config.h"
#include "WheelController.h"
#include "MCP3208.h"
#include "SensorConverter.h"
#include "S5851A.h"

// ---------------------------------------------------------------------------
// Instances
// ---------------------------------------------------------------------------
static MCP3208 extAdc(SPI0_CSN_PIN, SPI);
static S5851A  tempSensor(Wire, S5851A::I2C_ADDR);  // Board temperature sensor

static WheelController wheels[4] = {
    WheelController(MOTOR1_IN1, MOTOR1_IN2, ENC1_A, ENC1_B),
    WheelController(MOTOR2_IN1, MOTOR2_IN2, ENC2_A, ENC2_B),
    WheelController(MOTOR3_IN1, MOTOR3_IN2, ENC3_A, ENC3_B),
    WheelController(MOTOR4_IN1, MOTOR4_IN2, ENC4_A, ENC4_B),
};

// ---------------------------------------------------------------------------
// USB Serial receive state machine
// ---------------------------------------------------------------------------
static uint8_t  rxBuf[MAX_PACKET_DATA + 4];
static uint8_t  rxIdx      = 0;
static bool     rxInPacket = false;
static uint32_t rxStartMs  = 0;
static constexpr uint32_t RX_TIMEOUT_MS = 50;

// ---------------------------------------------------------------------------
// I2C1 slave state
// ---------------------------------------------------------------------------
// Read buffer: filled when controller sets a register address.
// onRequest() sends from this buffer.
static uint8_t  i2cReadBuf[64];
static uint8_t  i2cReadLen = 0;

// Write buffer: raw bytes received from controller in onReceive().
// Processed in loop() to avoid heavy work inside the ISR callback.
static uint8_t  i2cWriteBuf[32];
static uint8_t  i2cWriteLen  = 0;
static volatile bool i2cWritePending = false;

// ---------------------------------------------------------------------------
// External ADC buffer (updated periodically in loop, served from cache)
// ---------------------------------------------------------------------------
static int16_t  extAdcBuf[8] = {0};  // MCP3208 ch0..7, last sampled values
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

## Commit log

2026-03-07 Add PR2040_MotorDriver firmware with velocity/position control
    - Motor/Encoder/PID/WheelController classes for RP2040-based 4ch DC motor driver
    - DIRECT / VELOCITY (PID) / POSITION (cascade P+PI) control modes per wheel
    - I2C1 slave (0x60) and USB Serial binary protocol for controller communication
    - 200 Hz control loop, 100 Hz status packet (44 bytes: enc+vel+adc+timestamp)
    - VSCode IntelliSense config for arduino-pico (rp2040:rp2040 v5.5.1)
    - KiCad schematic/PCB files for PR2040_BASESYSTEM REV1.5.0
    [4ch LowPassFilter.kicad_sch, ADC subsystem.kicad_sch, Battery Protect 2Cell.kicad_sch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]
2026-03-08 Add MCP3208 ADC, SensorConverter, wheel physical params, and docs
    - MCP3208.h/cpp: 8ch SPI ADC driver (SPI0, 100Hz buffered sampling)
    - SensorConverter.h: INA213 current [A] and battery voltage [V] conversion
    - Config.h: wheel physical params (JGA25-370, dia=67.5mm, CPR≈827.2)
    CPS_TO_MMPS / COUNTS_TO_MM conversion factors
    - WheelController.h: added getVelocityMmps/setVelocityMmps,
    getPositionMm/setPositionMm physical unit methods
    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
2026-03-08 Add .gitignore and remove username from c_cpp_properties.json
    - .gitignore: exclude .claude/, KiCad lock/backup files, OS files
    - c_cpp_properties.json: replace hardcoded user path with ${env:LOCALAPPDATA}
2026-03-09 Add IMU support, differential drive control, and flash calibration persistence
    - Direct Wire IMU reads (MPU-6881/6500, WHO_AM_I=0x70), I2C auto-scan for 0x68/0x69
    - Madgwick AHRS filter at 100Hz (roll/pitch/yaw), IMU auto-retry every 2s
    - IMU calibration saved to RP2040 flash via EEPROM emulation, auto-loaded on boot
    - Differential drive body velocity control: CMD_SET_BODY_VEL (0x30), CMD_BODY_STOP (0x31)
    - monitor.py: body velocity display, IMU attitude, connection status
    - commander.py: drive/fwd/bwd/spin/bstop/imu/calibrate commands, fixed send_recv to filter by expected response type
    [Config.h, Encoder.cpp, PR2040_MotorDriver.ino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]
2026-03-10 Fix gear ratio to 51.45 (JGA25-370 51:1), add wheel calibration persistence
    - Config.h: ENCODER_GEAR_RATIO 18.8 → 51.45 (confirmed via wheelcal: scale=0.365)
    - Config.h: BODY_LEFT_DIR/RIGHT_DIR flipped to correct wheel rotation direction
    - Config.h: add CMD_SET_WHEEL_SCALE (0x33), WHEEL_BASE_MM 205→191.5 mm
    - PR2040_MotorDriver.ino: add wheelCalScale runtime variable applied in setBodyVelocity
    - PR2040_MotorDriver.ino: add WheelCalData struct, saveWheelCal/loadWheelCal (flash)
    - PR2040_MotorDriver.ino: handle CMD_SET_WHEEL_SCALE with sanity check (0.5–2.0)
    - WheelController.cpp: tune PID gains Kp 1.0→3.0, Ki 0.05→0.5 for higher CPR
    - commander.py: sync ENCODER_GEAR_RATIO, WHEEL_BAS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
    [Config.h, PR2040_MotorDriver.ino, WheelController.cpp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]
2026-03-10 Bake calibrated gear ratio 54.78 into config, reset wheel cal magic
    wheelcal measured scale=0.939244 with gear ratio 51.45, meaning the
    actual ratio is 51.45/0.939244=54.78. Embed this directly so wheelcal
    converges to ~1.0. Bump WHEEL_CAL_MAGIC to invalidate stale 0.939
    value in flash (firmware boots with wheelCalScale=1.0 until next wheelcal).
    [Config.h, PR2040_MotorDriver.ino, commander.py]
2026-03-15 Add S-5851A board temperature sensor support
    - Add S5851A driver library for I2C temperature sensor (AD0=GND, AD1=GND, addr=0x48)
    - Integrate 1Hz temperature sampling in main firmware loop
    - Add I2C register REG_BOARD_TEMP (0x60) for reading temperature via I2C
    - Add USB Serial command CMD_REQUEST_TEMP (0x15) and response RESP_TEMP (0x94)
    - Temperature sensor shares I2C0 bus with MPU-6881 IMU
    - Resolution: 0.0625°C (12-bit)
2026-03-15 Add ROS 2 Jazzy Docker setup with WebSocket-based edge architecture
    ## Docker Environment
    - Created ROS 2 Jazzy Docker environment for Debian 13 compatibility
    - Configured hardware access (I2C, camera) via device mapping
    - Built and tested container with mobile_robot_edge package
    ## Edge Services (Python WebSocket)
    - motor_service.py: Motor control via WebSocket (port 8001)
    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
2026-03-15 Migrate edge_services to USB serial communication
    Replace I2C-based PR2040 driver with USB serial interface based on
    CommandReference.md protocol. This provides more reliable communication
    and proper support for velocity control mode.
    New features:
    - PR2040USBDriver: USB serial driver implementing packet protocol
    - Proper packet format: [0xAA][CMD][LEN][DATA][CHECKSUM]
    - Handles 100Hz auto-status transmission from PR2040
    - Automatic VELOCITY mode initialization
    Configuration updates:
    - Updated robot_config.json with USB port settings
    - Changed encoder_cpr to calibrated value: 827.2 counts/rev
    - Replaced I2C settings with USB serial (115200 baud)
    Service updates:
    - motor_service.py: Now us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
    [launch_all.py, motor_service.py, odometry_service.py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]
2026-03-15 Add comprehensive documentation for Raspberry Pi setup
    Add detailed Japanese documentation for setting up the mobile robot
    system on Raspberry Pi, including installation, configuration, and
    troubleshooting guides.
    New documentation:
    - README.md: Project overview and quick start guide
    - System architecture diagram
    - Directory structure
    - Hardware specifications
    - Communication protocols
    - Known issues and development status
    - docs/raspberry_pi_setup.md: Complete setup guide
    - System requirements and prerequisites
    - Docker installation and configuration
    - Python environment setup
    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
2026-03-18 Fix Docker image build errors and add mobile_robot_server volume
    - Replace python3-cv-bridge with ros-jazzy-cv-bridge (correct package name)
    - Add mobile_robot_server volume mount to docker-compose.yml
2026-03-21 Fix edge services: background reader thread, DIRECT mode motor control
    - Rewrote PR2040USBDriver with background reader thread for non-blocking
    100Hz status packet parsing; motor commands use separate write lock
    - Switched motor control to DIRECT duty mode with dead-zone compensation
    (min duty 400 to overcome static friction, empirical max 7214 cps)
    - Right motor duty negated for mirrored physical mounting
    - Shared driver instance between motor and odometry services
    - Removed run_in_executor (driver is now fully non-blocking)
    - Confirmed working: WebSocket cmd_vel → forward motion verified
    [launch_all.py, motor_service.py, odometry_service.py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]
2026-03-21 Fix odometry: negate right encoder for mirrored wheel mounting
    Right wheels are physically mirrored, so encoder counts decrease
    when moving forward. Apply the same sign convention as motor_service
    (right_duty negated) to get correct differential drive odometry.
    Also initialize prev_encoders from current hardware values on startup
    to avoid large initial position jump from accumulated test counts.
    [odometry_service.py]
2026-03-29 Replace RTABMap with slam_toolbox, add autonomous mapping and foxglove_bridge
    - SLAM: replace RTABMap with slam_toolbox (async_slam_toolbox_node)
    - Input: /scan (BEST_EFFORT QoS matched) + /odom
    - Output: /map (5cm OccupancyGrid) + TF map→odom
    - Added lifecycle_manager_slam with bond_timeout=0 to activate node
    - Nav2 fixes:
    - collision_monitor: add min_range=0.15m to filter LiDAR self-reflections
    - local costmap obstacle_layer: obstacle/raytrace_min_range=0.15m
    - lifecycle_manager_slam added before nav2 in LaunchDescription
    - Add autonomous_mapping node (frontier-based exploration)
    - Subscribes: /map, /odom, /mapping/stop
    - Action client: /navigate_to_pose → bt_navigato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
    [autonomous_mapping.py, camera_service.py, dummy_camera.py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]
2026-03-29 Fix motor dead zone: calibrated PI+Feedforward with offset model
    Root cause: previous FF gain (0.139) was too low — at 0.5 m/s the FF
    output (277) was below MIN_DUTY (420), causing kickstart-then-stop loop.
    Calibration (duty_sweep.py, 2026-03-29):
    duty=460 → 853 cps duty=500 → 1685 cps duty=800 → 6700 cps
    Linear fit: duty = 402 + 0.0595 * cps
    Updated control law (offset feedforward model):
    ff = ff_offset + ff_gain * |target_cps|
    output = sign * ff + Kp * error + Ki * integral
    New: ff_offset=402, ff_gain=0.0595, min_duty=480
    Verification: 0.5 m/s (1994 cps) → FF = 402 + 0.0595*1994 = 521 ✓
    Added diagnostic tools:
    diagnose_motor.py — connection, calculation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
    [diagnose_motor.py, duty_sweep.py, motor_service.py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]
2026-03-29 Switch to firmware velocity PID: remove software PI+FF, program PR2040 gains
    Calibrated firmware velocity PID (kp=0.10, ki=0.40, kd=0.00) confirmed to
    reach 0.5 m/s in ~1.8s with steady-state error ±0.01 m/s. Python-side
    WheelVelocityController and pid_loop removed — firmware handles all control.
    Also adds duty_sweep.py (dead zone measurement) and diagnose_motor.py (diagnostic suite).
    [motor_service.py, pr2040_usb_driver.py]
2026-03-29 Fix: zero velocity targets after MODE_VELOCITY init to prevent runaway
    PR2040 firmware retains velocity targets across mode switches. Without
    an explicit zero command after _set_mode_all(MODE_VELOCITY), the firmware
    would resume driving to the previous session's target on startup.
    [pr2040_usb_driver.py]
2026-04-04 Switch AI pipeline to YOLO + Ollama (local): replace cloud GPT-4o with server-side YOLO object detection feeding qwen3.5:9b via Ollama
    - llm_nav_controller: default LLM endpoint → localhost:11434/v1 (Ollama)
    - llm_nav_controller: default model → qwen3.5:9b, vision_enabled=False, use_object_detection=True (YOLO)
    - llm_nav_controller: default YOLO model → yolov8s.pt (server GPU)
    - server_bringup: default llm_base_url → localhost:11434/v1, llm_model → qwen3.5:9b
    - server_bringup: add yolo_model launch arg, pass YOLO/vision params to llm_nav node
    - Update docstrings to document YOLO → Ollama pipeline
    [llm_nav_controller.py]
2026-04-04 Update system diagram: reflect YOLO + Ollama local AI pipeline
    - llm_nav_controller: show YOLO yolov8s.pt (RTX 4060) → Ollama qwen3.5:9b pipeline
    - Replace LM Studio (Nadia.local) with Ollama (localhost:11434/v1)
    - Update flow text: YOLO scene text → Ollama qwen3.5:9b (fully local)
    - Add GPU info note: RTX 4060 Laptop 8GB, CUDA 13.0
    - Update date to 2026-04-04
2026-04-04 Fix broken drawio XML: escape double quotes in flow_text attribute
    Unescaped " inside XML attribute value caused parse error.
    Replaced with &quot; entities.
2026-04-04 Add autonomous_mapping and foxglove_bridge to server_bringup, align LLM defaults
    Per system_diagram.drawio:
    - Add autonomous_mapping node (frontier detection, stuck_timeout=60s, /mapping/status)
    - Add foxglove_bridge node (WS :8765, all topics)
    - autonomous_mapping: default LLM URL → localhost:11434/v1, model → qwen3.5:9b
    [autonomous_mapping.py]
2026-04-04 Update diagram: YOLO + Ollama on Libra Ubuntu 24.04 host system
    - Add "Libra Ubuntu 24.04 Host System" frame (RTX 4060 / CUDA 13.0)
    - Split AI services into separate nodes: YOLO (yolov8s.pt) and Ollama (qwen3.5:9b)
    - Show YOLO → Ollama data flow (scene text) within host frame
    - Add host note: YOLO/Ollama run outside Docker on host OS
    - Update edge arrows: llm_nav → YOLO(①) → Ollama(②) → JSON response
    - Update foxglove_studio position to avoid overlap
    - Remove standalone GPU info note (now inside Libra frame)
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2026-04-04 TEST_LIBRA_AI: record T2 results — 8/8 PASS (2026-04-04) Fix: add YOLO .to('cuda') to ensure GPU inference on RTX 4060
    - Without explicit .to('cuda'), YOLO defaults to CPU (2372ms)
    - With .to('cuda'), inference is 7.1ms avg on RTX 4060
    - T2-5/T2-6: verified person detection on COCO bus.jpg sample
    [llm_nav_controller.py]
2026-04-04 Fix: YOLO+Ollama coexistence — disable thinking mode, use qwen3.5:9b-nav
    Problem: qwen3.5:9b thinking mode consumed 25-30s even with /no_think directive
    Solution:
    - Create Ollama model qwen3.5:9b-nav (num_ctx=2048, think=false)
    - Add think=False + num_ctx=2048 to all LLM API calls
    - Update default model to qwen3.5:9b-nav in llm_nav_controller and launch file
    Result: YOLO(GPU 7-19ms) + Ollama(1.0-1.6s) = 1.2-1.9s total pipeline
    VRAM: 6336/8188 MiB (YOLO+Ollama coexist within 8GB)
    [llm_nav_controller.py]
2026-04-04 TEST_LIBRA_AI: record T3 results — 9/9 PASS (2026-04-04)
    - T3-1/2: API accessible locally and externally (192.168.10.35:11434)
    - T3-3: model load 1.75s
    - T3-4/5/6: navigate/track/explore JSON format all correct
    - T3-7: think=false → no <think> tags in content (direct JSON)
    - T3-8: avg 1.26s (min 0.94s, max 1.55s) — well within 2s target
    - T3-9: VRAM 6059/8188 MiB
2026-04-04 TEST_LIBRA_AI: record T4 results — 7/7 PASS (2026-04-04)
    - T4-1: pipeline sequential OK (1.35s)
    - T4-2: navigate end-to-end with person image (turn_left, 1.68s)
    - T4-3: track end-to-end (turn_left, person_detected=True, pos=left)
    - T4-4: explore end-to-end (move_forward, 1.36s)
    - T4-5: latency avg 1.53s, min 1.34s, max 1.68s (target: <3s)
    - T4-6: 10x continuous, 0 errors, avg 1.63s
    - T4-7: VRAM 6298/8188 MiB (YOLO+Ollama coexist)
2026-04-05 TEST_LIBRA_AI: record T5+T6 results — 10/10 PASS
    T5 (異常系):
    - T5-1: Ollama停止 → APIConnectionError キャッチ・stop返却
    - T5-2: 不正JSON 5パターン → 安全処理
    - T5-3: frame=None → スキップ
    - T5-4: GPU OOM → RuntimeError捕捉・stop返却
    - T5-5: keepalive切れ → 自動再ロード 8s
    T6 (パフォーマンス):
    - T6-1: GPU最高62°C (< 90°C)
    - T6-2: VRAM変化+122 MiB (リークなし)
    - T6-3: CPU平均15.2% (< 80%)
    - T6-4: avg 1.69s / max 2.04s / 60サイクルエラーゼロ
    Fix: llm_nav_controller — OpenAI互換APIのthink=False無効化問題を修正
    - ollama Pythonパッケージを採用 (think=False確実動作)
    - qwen3.5:9b-nav: num_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
    [llm_nav_controller.py]
2026-04-05 Fix E3/E5/E6 tests: PID recal, odometry reset bug, closed-loop stopping
    Hardware/Control:
    - pr2040_usb_driver: ki 0.40→2.0 (dead zone overcome 3.4s→0.3s for rotation)
    - Minimum reliable angular velocity is 1.84 rad/s (dead zone = 440 duty)
    Odometry:
    - odometry_service: use enc[0]/enc[1] directly instead of 4-wheel average
    (enc[2]/enc[3] always 0; averaging caused 2× distance underestimate)
    - odometry_service: fix reset bug — call reset_encoders() before reset_odometry()
    so prev_encoders syncs with hardware zeros (was causing large spurious jumps)
    Test script:
    - verify_e3_e5_e6: get_odom() now drains stale buffered msgs, returns latest
    - verify_e3_e5_e6: E5/E6 use distance/angle-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
    [odometry_service.py, pr2040_usb_driver.py]
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2026-04-05 Fix verify_e1.py: drain odom buffer before get_status in all checks
    [verify_e1.py]
2026-04-05 Add E2 WebSocket port connection test; fix camera_service JSON encoding
    verify_e2.py:
    [1] 8001 motor: connect + stop ACK
    [2] 8002 odom: connect + initial odom message format
    [3] 8003 camera: connect + camera_info message (640×480 @ 30fps)
    Result: PASS 3/3 (2026-04-05)
    camera_service.py:
    - Fix: str(info) → json.dumps(info) for camera_info message
    - Add: import json
    [camera_service.py, verify_e2.py]
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2026-04-05 Fix encoder CPR: 827.2 → 2481.6 (gear ratio 3:1 was missing)
    Physical measurement from E5/E6 revealed odometry over-estimated by 3×:
    E5: odom=1.015m, physical=0.34m → ratio=0.335
    E6: odom=361.8°, physical=120° → ratio=0.332
    Both ≈ 1/3 → CPR_actual = 827.2 / 0.335 ≈ 2481.6 (= 827.2 × 3)
    After fix:
    E5: 1.2 cm error (< 5 cm) ✓
    E6: 0.30° error (< 5°) ✓
2026-04-05 E5: reduce linear velocity 0.3→0.15 m/s, tune STOP_AT 0.97→0.98
    Lower speed improves accuracy and reduces overshoot.
    Coast distance at 0.15 m/s ≈ 0.02 m (half of 0.3 m/s → STOP_AT 0.98).
    Result: 0.8 cm error, 0.0 cm lateral drift (was 1.2 cm / 0.5 cm at 0.3 m/s).
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2026-04-05 Calibrate wheel_base: 0.16→0.181m; tune E6 STOP_AT 0.984→0.990
    wheel_base calibration:
    Physical: outer=218mm, inner=166mm → geometric center=192mm
    Kinematic (from E6 odom/physical ratio): 0.16 × (356/315) = 0.181m
    Effective wheel_base=0.181m accounts for tire scrub during rotation.
    E6 STOP_AT tuned to 0.990 after wheel_base change.
    Result: E6 PASS — 0.58° error (< 5°)
    [verify_e6.py]
2026-04-05 Add IMU-based wheel_base calibration; update wheel_base 0.181→0.1839m
    calibrate_wheel_base.py:
    - Spins 360° while sampling IMU yaw (RESP_IMU 0x93, CMD_REQUEST_IMU 0x13)
    - Computes wheel_base correction: current × |gyro_deg| / |odom_deg|
    - Handles gyro Z-axis polarity mismatch (uses absolute values)
    - --apply flag auto-updates robot_config.json
    Result:
    odom=359.28°, gyro=364.97° → ratio=1.0158
    wheel_base: 0.181 → 0.1839 m
    E6 PASS: 2.61° error (< 5°)
    [calibrate_wheel_base.py]
2026-04-05 Add E7 odometry reset test (verify_e7.py)
    [1] Drive 0.5s to accumulate non-zero pose
    [2] Send {"type":"reset"} → x/y/theta == 0
    [3] Encoder counts reset to ~0
    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
    [verify_e7.py]
2026-04-05 Add E8 odom rate test; fix odometry publisher to deadline-based scheduling
    - verify_e8.py: new test measuring 50Hz publish rate (45-55Hz window, max interval <30ms)
    - odometry_service.py: replace sleep(interval) with deadline-based scheduling so
    processing time is absorbed and rate stays stable at 50Hz
    - VERIFICATION.md: mark E8 as implemented, add to coverage table
    [odometry_service.py, verify_e8.py]
2026-04-05 Add E9 camera image reception test (verify_e9.py)
    - Checks camera_info JSON on connect (width/height/fps/format)
    - Verifies binary frame received within 5s
    - Parses 8-byte header (float32 LE timestamp + uint16 width + uint16 height)
    with ±300s tolerance to account for float32 precision loss at current Unix time
    - Confirms JPEG SOI/EOI markers (FFD8/FFD9)
    [verify_e9.py]
2026-04-05 Add E10 camera fps test; fix camera_publisher to deadline-based scheduling
    - verify_e10.py: measures 30fps target (25-35fps window), verifies frame header
    width/height match config (640x480)
    - camera_service.py: replace sleep(interval) with deadline-based scheduling,
    fixing actual rate from 16.7fps to 30.3fps
    [camera_service.py, verify_e10.py]
2026-04-05 Add E11 velocity clamp test; fix motor_service ACK to return clamped values
    - verify_e11.py: tests linear/angular clamp in both directions and pass-through
    for in-range values
    - motor_service.py: store clamped values in current_linear/angular so ACK
    reflects actual commanded velocity rather than raw input
    [motor_service.py, verify_e11.py]
2026-04-05 Add E12 multi-client test; update VERIFICATION.md to all-implemented
    - verify_e12.py: verifies 2 simultaneous clients on odom and camera services,
    and that remaining client continues receiving after one disconnects
    - VERIFICATION.md: mark E9-E12 as implemented, fix coverage table (E3/E5/E6
    now reference individual scripts, add E8-E12 rows)
    [verify_e12.py]
2026-04-05 Add ROS 2 Docker container verification spec (ros2_docker/VERIFICATION.md)
    10 verification items (R1-R10) covering:
    - Container build, startup, network_mode:host WebSocket reachability
    - colcon build success for mobile_robot_edge / mobile_robot_server
    - Node launch (ws_motor_controller, ws_odometry_publisher, ws_camera_bridge,
    robot_state_publisher) and topic/TF correctness
    - End-to-end /cmd_vel → motor control
    - Camera compressed image publishing at 30Hz
    - WebSocket auto-reconnect after edge_services restart
    - Node respawn behavior
2026-04-05 R2 PASS: container startup and network_mode:host verified (2026-04-05)
    - Container starts as aarch64 Ubuntu 24.04 LTS
    - port 8001 motor: ACK {'type': 'ack', 'stopped': True}
    - port 8002 odom: type=odom x=0.000
    - port 8003 camera: type=camera_info 640x480
    - Fix R2 procedure: motor port needs stop cmd before ACK (no initial push)
2026-04-05 R3 PASS: colcon build verified for both packages (2026-04-05)
    mobile_robot_edge: 6.81s — 5 executables installed
    ws_motor_controller, ws_odometry_publisher, ws_camera_bridge,
    motor_controller, odometry_publisher
    mobile_robot_server: 6.80s — 2 executables installed
    llm_nav_controller, autonomous_mapping
    Summary: 2 packages finished [7.61s], no errors or warnings
2026-04-05 R4 PASS: 3 nodes confirmed via ws_edge_bringup.launch.py (2026-04-05)
    /ws_motor_controller, /ws_odometry_publisher, /robot_state_publisher — all up.
    ws_camera_bridge is server_bringup.launch.py only; corrected R4 from 4→3 nodes.
2026-04-05 R5 PASS: /odom 50Hz publish verified (2026-04-05)
    average rate: ~49.98 Hz, min: 18ms max: 22ms std: 0.8ms
    frame_id: odom, child_frame_id: base_footprint
    pose/twist covariance set correctly
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2026-04-05 Add Nav2 navigation stack verification spec (mobile_robot_server/VERIFICATION.md)
    12 verification items (N1-N12) covering:
    - N1: 9-node lifecycle startup (controller/smoother/planner/route/behavior/
    bt_navigator/waypoint_follower/velocity_smoother/collision_monitor)
    - N2: Required topics (/map, /odom, /scan) and TF chain (map→odom→base_footprint)
    - N3/N4: Global/local costmap publishing (5cm resolution)
    - N5/N6: navigate_to_pose action server + A* path planning
    - N7: Full navigation E2E (goal → arrive, short distance)
    - N8: velocity_smoother pipeline (cmd_vel_nav→smoothed→cmd_vel, 20Hz)
    - N9: collision_monitor emergency stop (LiDAR PolygonStop 0.35m)
    - N10: Recovery behavior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
2026-04-19 Add body STL models, LiDAR tilt module, and PowerBoard PCB design
    - BodyModel/: 3D printable STL files for robot chassis and mounts
    - LiderModule/: LiDAR tilt unit (firmware, host driver, 3D models, docs)
    - MotorDriver/PowerBoard/: KiCad PCB schematic and layout for power board
    [BaseBody.stl, BoltCap.stl, Center_body_upper.stl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]
2026-04-19 Fix foxglove_bridge optional in server_bringup; confirm N1 Nav2 lifecycle verification
    - server_bringup.launch.py: wrap foxglove_bridge Node in try/except PackageNotFoundError
    so the launch does not abort on systems without foxglove_bridge installed (e.g. Pi Docker)
    - mobile_robot_server/VERIFICATION.md: mark N1 (9-node lifecycle active) as 確認済み (2026-04-05)
    N1 confirmed: all 9 Nav2 nodes Configure→Activate→bond, "Managed nodes are active" logged
2026-04-19 Update Lider scan pattern and USB protocol docs
    [計測パターン.csv]
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2026-04-29 Integrate LiderModule ROS2 scanning
    [pattern_scan.ply, scan_step2.ply, t03_step10.ply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]
2026-04-30 Rebuild SLAM 2.5D stack from requirements
    [mobile_robot.urdf.xacro]
2026-04-30 Stabilize SLAM 2.5D scan/pointcloud flow and test procedure
    [lidar_tilt_3d.ino, lider_module_node.py]
2026-05-17 Add SLAM 3D LiDAR ICP stack and fix firmware/bridge bugs
    - lidar_pointcloud_bridge.py: new ROS2 node (USB CDC → PointCloud2)
    - BUG-3 fix: add last_scan_rx watchdog to detect stalled scan start
    masked by IMU heartbeat packets (50 Hz)
    - BUG-1 fix: cloud_frame=lidar_base_link / tilt_frame=lidar_tilt_link
    - lidar_tilt_3d.ino (BUG-2): CONTINUOUS mode now sends STATUS(2)+STATUS(0)
    at pass boundary so bridge publishes PointCloud2 each sweep
    - rpi_tilt_3d.py: CONTINUOUS mode no longer exits after first pass
    - rtabmap_lidar_3d_params.yaml: new config — ICP SLAM, subscribe_scan_cloud
    BUG-4: frame_id=base_footprint (was base_link) for correct Grid Z ref
    - slam_bringup.launch.py: new lau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
    [LiderBaseUnit.stl, LiderBaseUnit_Base_lower.stl, LiderBaseUnit_base_lower.stl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]
